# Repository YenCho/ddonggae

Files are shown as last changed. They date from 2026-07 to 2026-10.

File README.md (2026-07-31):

<div align="center">

# DDONGGAE&ensp;똥개

<h3><b>D</b>NN-based <b>D</b>etection of <b>O</b>bjects with <b>N</b>avigation<br>
and <b>G</b>oal-oriented <b>G</b>rasping for <b>A</b>utonomous <b>E</b>rrands</h3>

<p><b>An autonomous mobile manipulator that finds, identifies, grasps and stores 8 cm objects<br>
in a 4 m × 4 m arena inside a 3-minute round, computing everything on board a Jetson Orin Nano.</b></p>

<p><b>no Nav2&emsp;·&emsp;no AMCL&emsp;·&emsp;no TF tree&emsp;·&emsp;not one hand-labelled training image</b></p>

<p>🏆 <b>1st of 16 teams (우승)</b> — SNU AI ROBOT CHALLENGE 2026 (Seoul National University)</p>

<p>


</p>

<p>



</p>

<p>






</p>

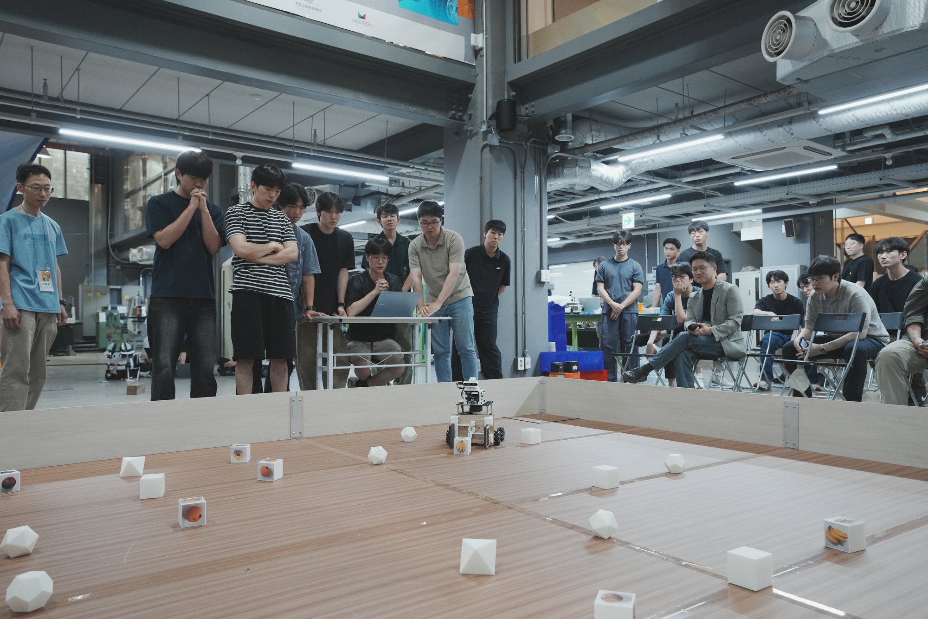
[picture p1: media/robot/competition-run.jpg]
DDONGGAE running a match in the 4 m x 4 m arena, carrying a fruit cube in its gripper while the other teams watch from behind the arena wall


<p><i>DDONGGAE mid-match: 28 white 3D-printed objects on a 50 cm grid, two announced target classes,<br>
180 seconds, one gripper — so every point is a round trip across the arena.</i></p>

<b><a href="#result">Result</a>&emsp;·&emsp;<a href="#what-it-does">What it does</a>&emsp;·&emsp;<a href="hardware/README.md">Hardware</a>&emsp;·&emsp;<a href="perception/README.md">Perception</a>&emsp;·&emsp;<a href="navigation/README.md">Navigation</a>&emsp;·&emsp;<a href="mission/README.md">Mission</a>&emsp;·&emsp;<a href="simulation/README.md">Simulation</a>&emsp;·&emsp;<a href="docs/README.md">Docs</a></b>

</div>

---

### Why 똥개?

**똥개** (*ddong-gae*) is Korean for a mongrel — a scruffy, unpedigreed street dog. It is an
insult and a term of affection at the same time, depending entirely on how you say it. Ours was
said with affection, at volume: **달려라 똥개** — *"run, mutt!"* — which became the team chant.

The name came from the robot's single most consequential limitation: one gripper, **one object at a
time**. That turns a match from a search problem into a running problem — drive out, pick up, run
it all the way back to the bin in the opposite corner, repeat. Seven objects in three minutes is
seven round trips, so the robot spends almost the whole match sprinting across the arena carrying
one cube. It is a very familiar image.

So the joke is also the design brief. A **25-second budget per object** falls straight out of it
(180 s ÷ 7), and nearly every engineering decision here — the free "highway" along the empty band
of the arena, the street router, deleting Nav2 for a localiser 17–22× faster, cutting rotation
because turning was collapsing the pose estimate — exists to make those round trips shorter.

<table>
  <tr>
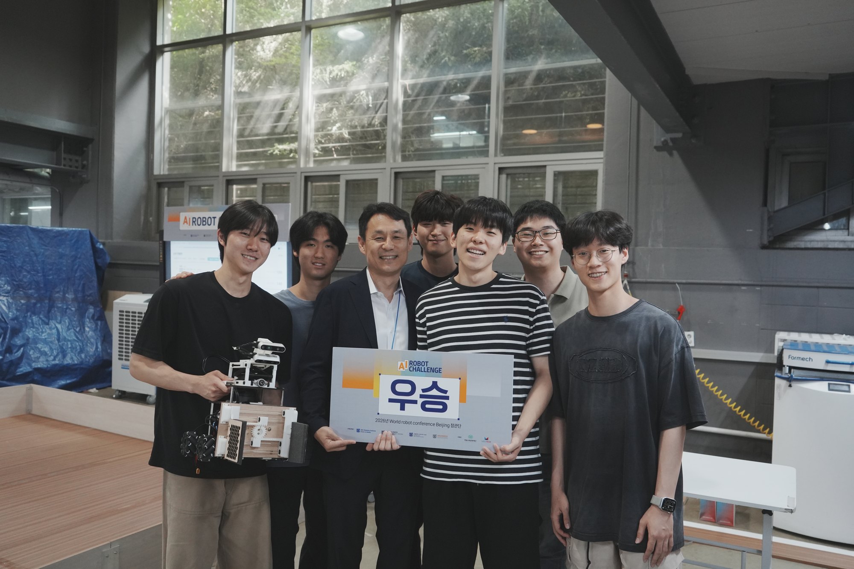
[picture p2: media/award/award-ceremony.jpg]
Team 14 holding the winners' placard and the robot
    <td width="50%"></td>
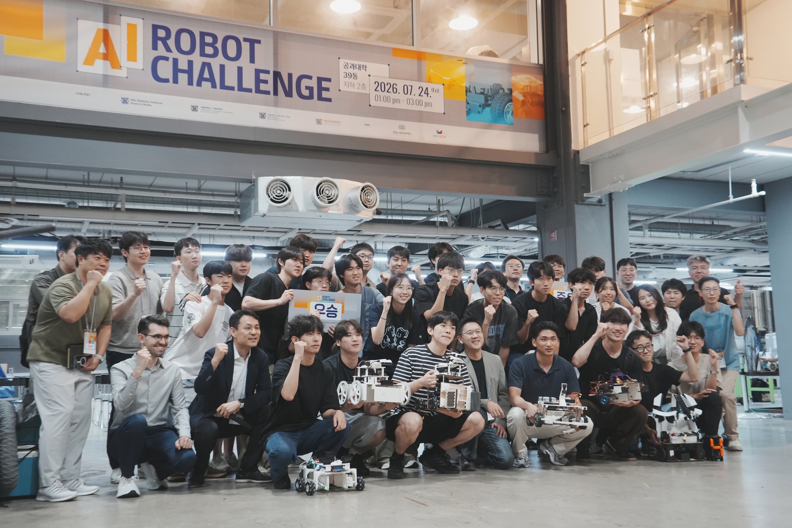
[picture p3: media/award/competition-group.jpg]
All SNU AI ROBOT CHALLENGE 2026 participants with their robots under the event banner
    <td width="50%"></td>
  </tr>
</table>

<!-- STILL TO ADD:
     VIDEO       replace every <YOUTUBE_URL> in this file, media/video/README.md
                 and docs/07-results-and-lessons.md with the organisers' recording URL -->

> Full competition video: `<YOUTUBE_URL>` *(to be added when the organisers publish it)*

---

## Result

**1st of 16 teams**, SNU AI ROBOT CHALLENGE 2026. Five teams reached the final; the final standing is
the sum of two matches, 200 points maximum, ties broken by fastest mission completion.

<picture>
  <source media="(prefers-color-scheme: dark)" srcset="docs/assets/final-standings-dark.svg">
  Final standings: Team 14 150, Team 7 140, Team 8 110, Team 16 100, Team 10 50 — each bar split into its two match scores
</picture>

Our two rounds, with the target classes drawn for each:

| | Targets | Collected | Score |
|---|---|---|---:|
| Final 1 | octahedron · pineapple | 3 fruit cubes | 60 |
| Final 2 | octahedron · banana | 3 shapes + 3 fruit cubes | 90 |

Scoring is 10 points per shape object and 20 per fruit cube, so one perfect match is 100 (4 shapes +
3 fruit cubes). We reached the final by placing in the qualifiers, which are weighted 10 % for the
first round and 90 % for the second; we scored 60 in both.

No match we ever ran was close to perfect, and we lost points three separate ways — all three are
documented at the same level of detail as the wins:

- **Qualifiers** — the apple printed on the arena cubes was a **yellowish, under-ripe apple**, not
  the red one announced beforehand. Our face model, trained on synthetic renders of a red apple,
  mis-predicted it. A textbook train/deploy colour domain gap.
- **Final 1** — the **gripper stopped reporting**. The robot routed to each object correctly, but
  the OpenRB board went quiet mid-match: one octahedron was carried and released without the grasp
  ever being confirmed (almost certainly an empty hand, and it scored nothing), and two more were
  refused outright because the gripper actively declared itself empty. Landing that one grasp would
  have made the match 70, not 60 — the run's own estimate. We also went 189.8 s against a 180 s
  budget, and the runner crashed on a seventh object seconds after it was dropped in.
- **Final 2** — **ran out of time.** The 180 s timeout expired while the last object was being
  grasped, and only what is inside the box at time-up scores.

Full post-mortem with measured numbers: [`docs/07-results-and-lessons.md`](docs/07-results-and-lessons.md).

---

## What it does

The robot starts in a 40 × 40 cm corner zone of a 4 m × 4 m walled arena that contains 28 white
3D-printed objects on a known 42-point, 50 cm grid — polyhedra worth 10 points each and cubes with
fruit photographs on three of their six faces worth 20 each. Two target classes are announced, the
second of them **one minute** before the start signal, after which nobody may touch the computer.
Within 180 seconds and with every computation on board a Jetson Orin Nano, it drives to the arena
centre, raises a camera mast, takes twelve stitched captures at 30° steps, votes each detection onto
the 42-cell grid, then works through the confirmed targets — the 20-point fruit set first, and in
the two finals ranked by expected value rather than distance — re-verifies each identity at close
range, grasps it, carries it to the storage box at the far end of the start wall and drops it on a
precomputed slot. Picking up the wrong object costs twice its value, so refusing to pick is a
legitimate — often optimal — outcome, and the collection loop is built around that asymmetry.

```mermaid
flowchart LR
  subgraph SENS["Sensors"]
    direction TB
    CAM["2x RealSense D435/D435i<br/>on a lifting mast"]
    LID["RPLIDAR A2M12"]
    IMU["D435i gyro-z"]
  end

  subgraph ROS["ROS 2 Humble — one process per device, plus two brains"]
    direction TB
    RS["realsense2_camera x2"]
    SLL["sllidar_node<br/>+ scan watchdog"]
    RUN["match_runner.py<br/>stitch -> A1 -> face -> depth -> 42-cell grid<br/>+ the match state machine"]
    ARENA["arena_control_node<br/>known-map wall-range localisation<br/>+ mecanum goal controller"]
    MUX["cmd_vel_mux"]
    MEC["mecanum_bridge_node"]
    GRIP["gripper_bridge_node"]
  end

  subgraph ACT["Actuators — firmware owns the loops"]
    direction TB
    UNO["Arduino UNO<br/>4x wheel velocity PID<br/>+ trapezoidal position moves"]
    ORB["OpenRB-150<br/>Dynamixel XC330 x2"]
    WHL["4 mecanum wheels"]
    GM["parallel gripper + camera mast"]
  end

  CAM --> RS -->|"RGB 1920x1080 + aligned depth"| RUN
  LID --> SLL -->|"/laser_scan"| ARENA
  IMU -->|"/imu/data"| ARENA
  RUN -->|"STOP, then JSON goal {x,y,yaw} (fallback path)"| ARENA
  ARENA -->|"/arena_lightweight/status — pose at 20 Hz"| RUN
  RUN -->|"/cmd_vel_direct at 20 Hz (street closed loop)"| MUX
  ARENA -.->|"/cmd_vel_direct (goal following, fallback)"| MUX
  MUX --> MEC
  RUN -->|"/base/move_relative"| MEC
  RUN -->|"/gripper/command, /lift/command"| GRIP
  MEC -->|"serial 115200"| UNO --> WHL
  GRIP -->|"serial 115200"| ORB --> GM
```

Nine long-lived processes, no custom message package — every structured payload is a
`std_msgs/String` carrying JSON, so the whole graph is `ros2 topic echo`-readable with nothing
built. The exhaustive graph, with every topic, QoS profile, JSON schema and serial line, is in
[`docs/03-ros2-interfaces.md`](docs/03-ros2-interfaces.md).

The solid `/cmd_vel_direct` edge is the one that carried every match. The mission runner sends the
arena node a `STOP` first — releasing its goal following — and then drives the base itself at 20 Hz
through [`navigation/street_nav.py`](navigation/street_nav.py), because the corridors are only
25 cm wide and the gripper sticks 26 cm out in front. Goal following is the dashed edge: the
fallback we kept for the legacy route (`--nav legacy`).

---

## The three parts

### [Hardware](hardware/README.md)

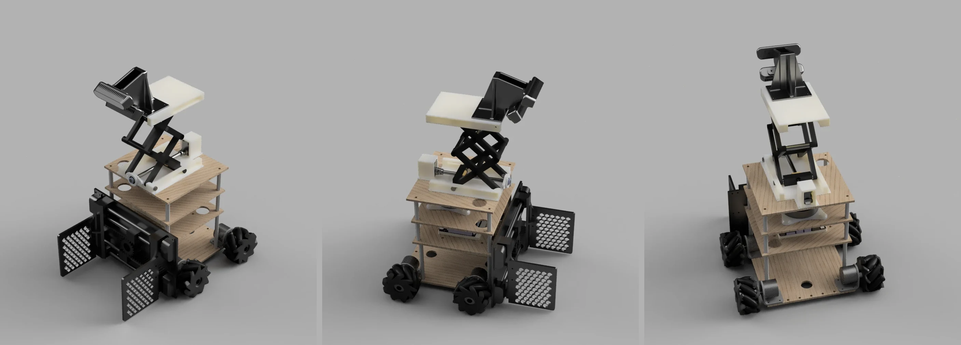
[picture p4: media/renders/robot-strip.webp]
The DDONGGAE robot rendered from three angles 120 degrees apart, mast raised


A 4-wheel mecanum base with a three-deck plate stack, a servo-driven camera mast carrying both
RealSense units, and one parallel gripper. The mast exists for one reason: it goes up for the
centre scan. A fruit cube's three photographed faces are its top and one opposing pair of sides,
so the **top** face is the only one visible from every direction — from chassis height it is
edge-on and contributes nothing, and whether you see a photograph at all comes down to which way
the cube happens to be turned. The 148.9 mm of stroke puts the top camera at 0.4986 m and steepens
the look-down enough to read those top faces, while also cutting how much the objects occlude each
other. Two microcontrollers own all motion primitives: an
Arduino UNO runs the four wheel-velocity PIDs and synchronised trapezoidal position moves
(`d dx dy dyaw` → `DONE,move`), and an OpenRB-150 owns the gripper and the mast lift on a single
tty. The headline fact is that two of the drive constants are **fitted, not measured** —
`wheel_radius_m` 0.0388 against a physical 0.040, and a rotation geometry of 0.198 m against a
physical 0.275 m — because a commanded 90° yaw produced 158° of real rotation until they were
recalibrated against the gyro. Copy the physical values and every position move is wrong.

### [Object detection](perception/README.md)

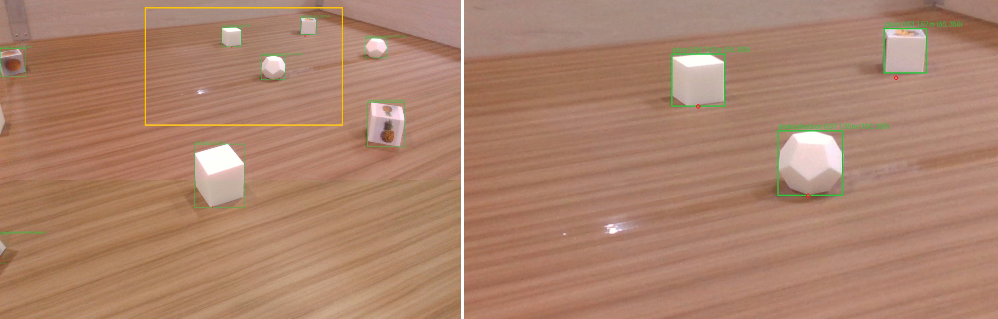
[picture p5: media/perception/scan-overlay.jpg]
A1 and face detections drawn on a stitched arena frame during the centre scan, with an enlarged panel showing the per-detection labels


Three stages, in the configuration that played the finals: full-frame A1 shape segmentation on the
stitched dual-camera frame (`cube_like_object` / octahedron / dodecahedron / icosahedron), then
every cube crop batched into one 224 × 224 BGR face-identity pass (apple / orange / banana /
pineapple / plain), then a binary pair verifier (MobileNetV3, ONNX) as a second opinion on the
fruit faces, then depth back-projection into the map and a per-cell vote across the 12-shot spin.

Both YOLO stages started from **zero hand-labelled images** — the training set was rendered in
BlenderProc. That stopped being the whole story on the last night: the face weight that played the
two finals is a fine-tune on photographs of the actual arena objects, hand-checked by an operator,
and the banana/pineapple verifier that ran beside it was retrained the same way. On a held-out
arena set (60 scenes, 573 objects) A1 scores box mAP50 0.831 / mAP50-95 0.729 — published next to the
0.9941 it scores on the split it was trained on, because that is the number that would have
fooled us.

### [Navigation](navigation/README.md)

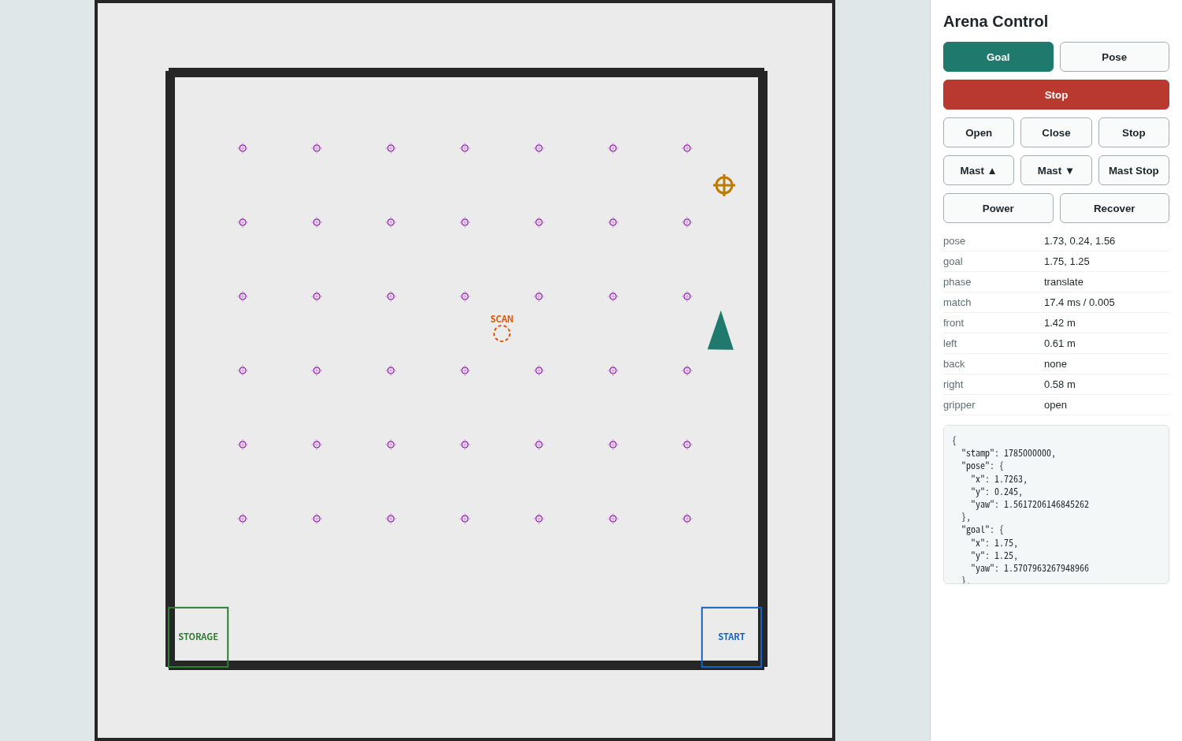
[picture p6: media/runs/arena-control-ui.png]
The arena control web UI: the 42-point grid, the storage and start zones, the scan point, the robot pose and the clicked goal, beside a panel of buttons and live metrics


One `rclpy` node, no Nav2 and no framework underneath it. The arena is a known empty rectangle and
the LiDAR plane at 0.32 m clears every 8 cm object, so every return is a wall: the localiser scores
each beam against the **analytic** ray/rectangle range of the four walls, ~30 float operations per
beam, pure Python standard library with no numpy in the hot path.

The approach we replaced — generic occupancy-grid scan matching, the Nav2/AMCL way — took
**345–449 ms** per solve on this robot. Ours takes **20.35 ms** on a synthetic 1080-beam scan and a
median of **28.2 ms** on the Jetson across 2,132 real scans. At a 10 Hz LiDAR that is the difference
between running 3–4 scans behind and comfortably inside one scan period; the old latency is why the
pose used to jump and the driven path used to bend. Yaw comes from integrating gyro-z forward
between scans, which is what makes a 90°-symmetric square arena solvable at all.

The mission layer that drives all three — [`mission/match_runner.py`](mission/README.md), 5,291
lines — and the [Isaac Sim kinematic surrogate](simulation/README.md) that ran the *same* file
against ground truth are documented separately.

---

## Highlights

- **We deleted Nav2 and measured why.** Full occupancy-grid scan matching: 345–449 ms per solve,
  with pose yaw jumping and driven paths bending. The closed-form wall-range replacement is ~90
  lines and 17–22× faster. The price is stated too: the map must be a known correct rectangle, the
  initial pose must be seeded by an operator, and there is no dynamic obstacle avoidance worth the
  name. [ADR-0001](docs/adr/0001-drop-nav2.md).
- **Every weight started from BlenderProc renders — and the last night broke that.** Right up to the
  qualifiers, nothing in the project had been hand-labelled: when the organisers clarified the face
  rule four days out, the fix was three lines and a re-render instead of a re-annotation. Then the
  arena's apple turned out to be the wrong colour, and the answer was photographs of the real
  objects, an operator relabelling ~74 crops by eye and dropping ~60 more, and an overnight
  fine-tune. That weight, and a banana/pineapple verifier retrained the same way, are what played
  the two finals. The synthetic-only claim is true of the qualifiers, not of the trophy.
- **Two runtime contracts that fail silently.** Mind the RGB↔BGR convention, and mind the gap
  between the size the model was trained at and the `imgsz` it is called with on the robot. Get
  either wrong and accuracy collapses — with no error raised and every log line still looking
  healthy. Details in [`perception/docs/models.md`](perception/docs/models.md).
- **Batch, don't loop: 3.86×.** Five crops through one `predict()` call take 10.9 ms; the same five
  crops in a Python `for` loop take 42.2 ms. Nothing about the model changes. The same discipline
  took the whole pipeline from 1.29 FPS (the earlier 4-stage cascade) to 3.83 FPS on an identical
  30 s capture.
- **The street router.** Because the rulebook only ever places objects on a 50 cm grid, the midlines
  between grid rows and columns are 25 cm corridors that are free *by construction* — so the router
  snaps onto a fixed street grid and verifies clearance instead of inflating a costmap (a 0.31 m
  circumscribed inflation marks every legal street blocked). After the 2026-07-20 fix: 0 of 28
  targets intruded on an object cell, minimum clearance 0.250 m, against 6 intrusions and 4.8 cm
  before it.
- **Sensorless grasp verification.** The gripper has no force sensor and its current reading is
  useless (an empty hand saturates at ~113 raw against a goal of 120). The *settled finger-position
  gap* separates cleanly instead: 3.0–3.2° empty versus 14.1° holding an icosahedron, threshold
  8.0°, and the whole check fits in 0.85 s.
- **The match was planned in simulation, not on the robot.** A perfect round is 7 objects in 180 s
  — a **25-second budget per object** — and a wrong pickup costs *double* the object's value. The
  Isaac Sim kinematic surrogate runs `mission/match_runner.py` unmodified against known ground
  truth, with a per-object phase breakdown (route / face / approach / grasp / carry), so time could
  be attributed rather than guessed at. That is where excess rotation was identified as the thing
  collapsing the localiser, and where an ~8 s deadband-parking-plus-settling grind was found and
  removed. No physics required — just the real state machine, a real map and a clock.
  [`simulation/README.md`](simulation/README.md)

---

## Quickstart

Three of these need no robot, no GPU, no ROS installation and no model weights.

```bash
git clone https://github.com/YenCho/ddonggae
cd ddonggae

# 1. the mission logic, self-testing: GT parser, street router (incl. the 28-object
#    regression case), 42-cell snap, storage slot layout, competition candidate filter
python3 mission/match_runner.py --offline

# 2. the unit tests that need no ROS — 47 pass in ~2 s
#    (localisers, mecanum kinematics + odometry, stitch geometry, grasp alignment, web UI)
python3 -m pytest tests/ -q --ignore=tests/test_controllers.py

# 3. with ROS 2 Humble: build the four packages, then run the full suite
source /opt/ros/humble/setup.bash
colcon build --symlink-install --base-paths hardware/ros2 navigation/ros2 third_party
source install/setup.bash && python3 -m pytest tests/ -q

# 4. the perception weights (not in git — Ultralytics derivatives, AGPL-3.0)
scripts/fetch_models.sh
```

`match_runner.py --offline` prints its self-test in Korean; the shipped script logs in Korean
throughout, and the reasoning in those log lines and code comments is translated into these docs
rather than deleted.

Then: [`docs/04-getting-started.md`](docs/04-getting-started.md) to bring the stack up on a robot,
and [`docs/05-field-runbook.md`](docs/05-field-runbook.md) for the competition-day procedure as it
was actually operated. Read [`docs/04` §10](docs/04-getting-started.md) first if you intend to
reproduce results — the stitch calibration, the camera mount geometry, the venue photometry and the
TensorRT engines are ours and do not transfer.

---

## Repository layout

```
.
├── hardware/        the machine: Arduino UNO + OpenRB-150 firmware, the two ROS 2 bridge
│                    packages, the numbered 00..53 bring-up/calibration chain, URDF + meshes
├── perception/      fieldlib.py (the shared runtime contract), geometry.py, the stitch and
│                    photometry calibration, training entry points, offline evaluators
├── navigation/      arena_lightweight_control — the entire Nav2-free localisation and
│                    control stack, its map, its launch file and its web operator console
├── mission/         match_runner.py, the 5,291-line program that played every match, plus
│                    field_autopilot.py (bring up / health-check / capture / teleop / down)
├── simulation/      Isaac Sim kinematic surrogate: same topics, same mission file, known
│                    ground truth. Explicitly not a physics validator
├── docs/            01..08 numbered guides, five ADRs, CREDITS  ->  docs/README.md
├── scripts/         the wrappers actually typed in the field, run_match_day.sh first
├── tests/           pytest; no robot, no GPU
├── third_party/     vendored sllidar_ros2 (BSD-2), pinned to the revision that competed
└── media/           robot renders, competition photographs, the scan clip and run figures
```

---

## What didn't work

Three ideas that looked obviously correct, were built, were measured, and lost — a binary
apple-vs-orange / banana-vs-pineapple verifier pair that was *more* accurate in isolation yet cost
11 points of face-level accuracy as a decision rule (85.7 % with verifiers off versus 74.3 % for the
best gated configuration, over a 780-configuration sweep on 175 real face patches) — though that
verdict was about the *synthetic-trained* verifiers, and a banana/pineapple one retrained on real
photographs earned its place back in the finals; a distance gate
that was tuned for three weeks and turned out to be masking a two-line inference bug; and
ground-contact ranging, which is exact for a cube and systematically long for a sphere-like
polyhedron, producing 0/4 icosahedron grasps on 2026-07-20 before it was replaced by depth
sampling.

All three, plus the three competition failures and ten transferable lessons, are in
[`docs/07-results-and-lessons.md`](docs/07-results-and-lessons.md).

---

## Team

Seven people built this robot. Names, GitHub accounts, how the work split, and the tooling
disclosure are in [`docs/CREDITS.md`](docs/CREDITS.md).

---

## License, citation, acknowledgements

The code and documentation in this repository are **MIT** licensed ([`LICENSE`](LICENSE)). Two
things in it are not:

- **Model weights** are Ultralytics YOLO derivatives and therefore **AGPL-3.0**. They are published
  as GitHub Release assets, fetched by `scripts/fetch_models.sh`, and are not in this tree.
- **Training textures and backgrounds are not redistributed.** The fruit-face texture pool is
  built from three public datasets (65 % Fruits-360, CC BY-SA 4.0, among others — web-scraped
  images were deliberately excluded), but the share-alike and attribution obligations, and the
  COCO 2017 background terms, are theirs to carry; only the generation and filtering scripts are
  published. See [`NOTICE`](NOTICE) for the full third-party list, including the vendored Slamtec
  `sllidar_ros2` driver (BSD-2-Clause).

The competition rules are the organisers' property and are paraphrased, never reproduced, in
[`docs/01-competition-and-rules.md`](docs/01-competition-and-rules.md).

To cite this work, use [`CITATION.cff`](CITATION.cff) (GitHub's "Cite this repository" button reads
it directly):

```bibtex
@software{ddonggae_2026,
  title  = {DDONGGAE: an autonomous polyhedron-collecting robot},
  author = {Cho, Yeonwoo and Kim, Jaeyoung and Jang, Minjoon and Lim, Junhwan
            and Kim, Minseok and Kim, Junseo and Han, Seojun},
  year   = {2026},
  url    = {https://github.com/YenCho/ddonggae},
  license = {MIT}
}
```

**Acknowledgements** — the organisers of the SNU AI ROBOT CHALLENGE 2026
for the arena, the rulebook and the venue; Slamtec, ROBOTIS, Intel RealSense, NVIDIA (Isaac Sim),
Ultralytics and the BlenderProc and Blender projects, whose work this robot is built on top of and
whose licences are enumerated in [`NOTICE`](NOTICE).

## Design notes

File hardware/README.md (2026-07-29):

# Hardware

<p align="center">
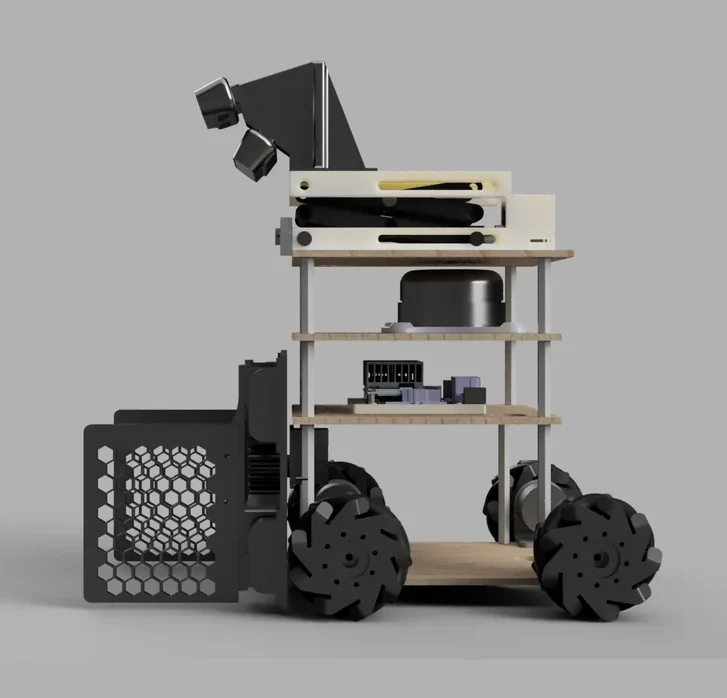
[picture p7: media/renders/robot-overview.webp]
Render of the DDONGGAE robot from the side: mecanum base, three equipment decks, the lowered camera mast and the parallel gripper
  
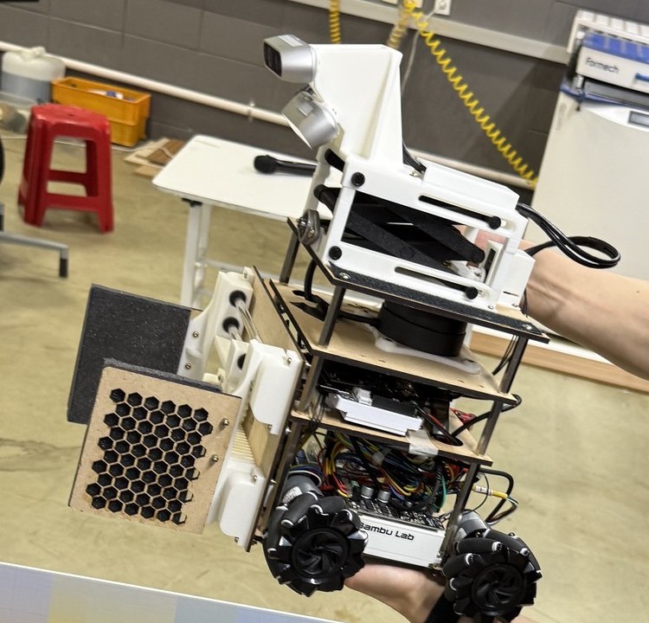
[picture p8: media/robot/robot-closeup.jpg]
The robot as built, held up after the final: hex-mesh gripper jaws, the mast with both RealSense units, the lidar, the wired decks and the mecanum wheels
  
</p>
<p align="center"><em>The CAD and the thing that played the matches, from about the same angle.
Wheel centres are 0.30 m front to rear and 0.25 m across.</em></p>
Everything on this robot that touches a wire: two firmware images, the two ROS 2 packages
that speak their serial protocols, the calibration constants those bridges load, the
bring-up chain that measures those constants, and the CAD.

This is the machine that won 1st place of 16 teams at the SNU AI ROBOT CHALLENGE 2026 (qualifiers 60 + 60 pts, finals 60 + 90 = 150 pts).

---

## 1. What the robot is

A 4-wheel mecanum differential-strafe base, roughly 0.30 m (wheel centre to wheel centre,
front to rear) × 0.25 m (left to right), with a three-deck plate stack, a servo-driven
camera mast, and a single parallel gripper at the front. It works a 4 m × 4 m arena in
3-minute rounds: find objects on a known 42-point grid, drive to one, grasp it, carry it
to the storage box, repeat.

| Subsystem | What it is | Where it is defined |
|---|---|---|
| Drive | 4 × JGB37-520 12 V 333 rpm gearmotor with quadrature encoder, mecanum wheels in X configuration | [`docs/wiring-and-firmware.md`](docs/wiring-and-firmware.md) |
| Motor drivers | 2 × Cytron MDD10A (2 channels each, PWM + DIR sign-magnitude) | [`docs/wiring-and-firmware.md`](docs/wiring-and-firmware.md) |
| Motion controller | Arduino UNO — 4 encoders, 50 Hz velocity PID, cascaded position loop, trapezoidal profiles | `firmware/arduino_mecanum/mecanum_encoder_control.ino` |
| Gripper | Dynamixel XC330 (ID 0), parallel jaws, current-based position mode | [`docs/gripper-and-mast.md`](docs/gripper-and-mast.md) |
| Camera mast | Dynamixel XC330 (ID 12), multi-turn lift, 148.9 mm measured stroke | [`docs/gripper-and-mast.md`](docs/gripper-and-mast.md) |
| Servo controller | OpenRB-150 — one USB tty, one Dynamixel bus at 1 Mbps, Protocol 2.0 | `firmware/openrb_gripper_mast/openrb_gripper.ino` |
| Cameras | Intel RealSense D435 (top) + D435i (near) — both ride the mast | `ros2/robot_bringup/launch/real_competition_bridge.launch.py` |
| LiDAR | Slamtec RPLIDAR A2M12, 256000 baud, mounted at `base_link` z = 0.262 m, yaw = π | `ros2/robot_bringup/launch/real_competition_bridge.launch.py:192-212` |
| Gyro | The D435i's IMU (`enable_bottom_imu` default `true`, remapped to `/imu/data`) — used by the localizer to make arena yaw observable | `ros2/robot_bringup/launch/real_competition_bridge.launch.py:57-58,150` |
| Compute | NVIDIA Jetson Orin Nano — the two RealSense units and the LiDAR plug into it directly; the UNO and the OpenRB-150 go through a powered USB hub, which held their ttys far more reliably than the Jetson's own ports did | [`docs/wiring-and-firmware.md`](docs/wiring-and-firmware.md#2-boards-buses-and-who-owns-what) |
| Power | 12 V battery → both MDD10A boards; encoders and logic off the Arduino 5 V rail; common ground is mandatory. Boot the Jetson with the 12 V kill switch **off** and switch it on afterwards, or the OpenRB-150 will not enumerate reliably | [`docs/wiring-and-firmware.md`](docs/wiring-and-firmware.md#boot-the-jetson-with-the-12-v-kill-switch-off) |

<p align="center">
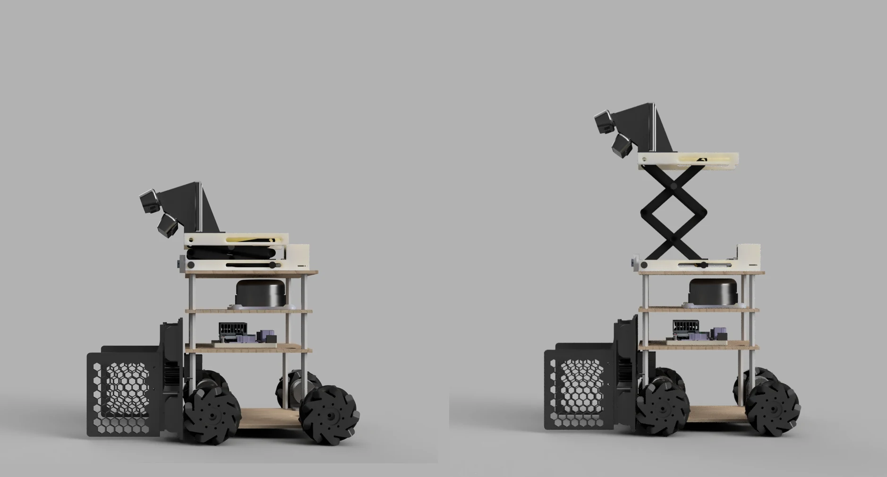
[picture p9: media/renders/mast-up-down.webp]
The robot rendered from the side with the camera mast lowered and raised, at the same scale and ground line
  
</p>
<p align="center"><em>The one moving part that changes what the robot can see: the mast down (left) and up
(right), same scale, same ground line. The stroke is 148.9 mm measured. Both RealSense units ride the
top plate, so the two heights are two camera extrinsics and two stitch calibrations — most of what
<a href="../perception/README.md">perception/</a> has to keep straight follows from this picture.</em></p>

It goes up for exactly one thing: the centre scan. What separates a 20-point fruit cube from a
10-point plain one is a photograph on three of its six faces — the **top** face and one opposing
pair of sides. Only the top face is visible from every direction: the two fruit sides face away
half the time, depending on how the cube was set down. And from chassis height the top face is
edge-on, contributing a few pixels at the 1–2 m ranges the scan works at. So a mast-down scan is
left guessing on cube identity from an unlucky yaw. The 148.9 mm lift steepens the look-down enough
to read the top faces regardless of yaw, and buys less mutual occlusion between objects across a
2.15 m scan radius on the way. Everything else in the match runs mast-down — the pre-shot and the
pre-grasp re-check are both short-range work for the near camera — which is why the descent is
commanded the instant the last scan frame is taken. Full argument, with the measured fruit-face
hit rates: [`perception/docs/grid-voting.md`](../perception/docs/grid-voting.md).

Deck geometry, as modelled in `cad/urdf/robot_mk3_mecanum_sim_80mm.urdf` (collision boxes,
so these are the plate outlines, not machining drawings):

| Deck | Size | Height above ground |
|---|---|---|
| Lower plate | 190 × 250 × 6 mm | 0.173 m |
| Middle plate | 190 × 210 × 6 mm | 0.258 m |
| Upper plate | 190 × 170 × 6 mm | 0.333 m |

Modelled chassis mass is 2.4 kg (simulation value, not a weighed figure).

### Three microcontrollers, three rules

1. **Arduino UNO owns motion.** It is not a dumb PWM slave. Geometry, both PID sets,
   per-wheel motor and encoder polarity and even the driver's PWM encoding style are all
   runtime serial commands, and a single `d <dx> <dy> <dyaw>` makes the firmware run a
   synchronized 4-wheel trapezoidal move and report the residual error per wheel. There is
   no host-side control loop on the mecanum path.
2. **OpenRB-150 owns the gripper *and* the mast, on one tty.** Opening that serial port
   from a second process toggles DTR, reboots the board, wipes the mast's RAM-held home
   position and force-opens the gripper. Exactly one process may hold it — see
   [the one-process rule](docs/gripper-and-mast.md#5-one-process-owns-the-tty).
3. **The LiDAR is treated as unreliable by design.** `laser_scan_watchdog_node`
   republishes `/scan_raw` at a fixed rate onto `/laser_scan` (+ a `/scan` alias), holds a
   stale scan for a bounded window and can emit an explicit empty scan on total loss, so
   the localizer never sees a gap.

---

## 2. Directory map

```
hardware/
├── firmware/
│   ├── arduino_mecanum/mecanum_encoder_control.ino   THE flashed competition firmware (UNO)
│   └── openrb_gripper_mast/openrb_gripper.ino        THE flashed competition firmware (OpenRB-150)
├── ros2/
│   ├── robot_hardware/      mecanum_bridge_node, gripper_bridge_node, kinematics, odometry
│   └── robot_bringup/       real_competition_bridge.launch.py, cmd_vel mux, scan watchdog, real.yaml
├── bringup_tools/           numbered rebuild chain 00..53 (flash → signs → CPR → PID → LiDAR → accuracy)
├── calibration/motor_pwm/   PWM→rad/s sweeps (legacy differential-drive generation)
├── cad/
│   ├── urdf/                mecanum URDF (80 mm wheels) + the generator that produced it
│   ├── meshes/              STL visual meshes referenced by the URDF
└── docs/
    ├── bom.md                    bill of materials
    ├── wiring-and-firmware.md    pin map, MDD10A, both serial protocols, the PID cascade
    └── gripper-and-mast.md       sensorless grasp detection, mast homing, the one-tty rule
```

ROS 2 nodes shipped here (`ros2/robot_hardware/setup.py`, `ros2/robot_bringup/setup.py`):

| Node | Role |
|---|---|
| `mecanum_bridge_node` | **The competition base driver.** `/cmd_vel_motor` → serial `m`; `/base/move_relative` → serial `d` → `/base/move_result`; `STATE` stream → `/chassis/odom`, `/joint_states`, `/motor/state` |
| `gripper_bridge_node` | Sole owner of the OpenRB tty. `/gripper/command`, `/lift/command` → serial; `/gripper/state`, `/lift/state`, `/gripper/grasp` |
| `cmd_vel_mux_node` | Priority mux `/cmd_vel_direct` > `/cmd_vel` > `/cmd_vel_nav` → `/cmd_vel_motor`, each with a 0.4 s staleness timeout, zero Twist at 30 Hz when all sources go stale |
| `laser_scan_watchdog_node` | `/scan_raw` → `/laser_scan` + `/scan`, fixed rate, bounded stale-hold |
| `motor_bridge_node` | **Legacy** differential-drive driver (MK3, host-side PI + calibrated PWM feedforward). Superseded by the 2026-07-14 mecanum conversion; retained so the diff→mecanum history is legible |

---

## 3. How to rebuild it

### 3.1 Order the parts

Start from [`docs/bom.md`](docs/bom.md). Two things there are not substitutable without
code changes:

- **All four motors must have encoders.** The position loop is per-wheel; a rear wheel
  without an encoder cannot participate in a synchronized move.
- **The motor driver must be sign-magnitude (PWM = speed, DIR = direction).** The firmware
  supports the older inverted-PWM style too, but only as a runtime `mstyle` switch, and
  the shipped defaults assume MDD10A.

### 3.2 Assemble and wire

Follow [`docs/wiring-and-firmware.md`](docs/wiring-and-firmware.md). The one mechanical
trap: mecanum wheels must be mounted in **X configuration** viewed from above (FL/RR
rollers tilt one way, FR/RL the other). Mount them in O configuration and every strafe
command becomes a rotation.

### 3.3 Flash and calibrate

The bring-up chain in `bringup_tools/` is numbered in execution order, and **each script
prints the exact constants to paste into `ros2/robot_bringup/config/real.yaml`**. Scripts
00–31 talk to the Arduino over raw serial and require the ROS bridge to be stopped; 40+
require the ROS stack to be running.

| Step | Tool | What it produces | Robot state |
|---|---|---|---|
| 00 | `00_flash_firmware.sh` | Compiles and uploads via `arduino-cli` (`arduino:avr:uno`) | Bridge stopped |
| 10 | `10_wheel_selftest.py` | The firmware `sign` line and the `motor_signs` / `encoder_signs` YAML snippet | On blocks, wheels free |
| 20 | `20_encoder_cpr_calib.py` | `encoder_cpr` — turn each wheel N revolutions by hand and count ticks | On blocks |
| 30 | `30_pid_step_tune.py` | Velocity PID gains from step responses (rise / overshoot / steady-state error per wheel) | On blocks |
| 31 | `31_pid_floor_verify.py` | Re-verifies those gains **under floor load**, forward and reverse | On the floor |
| 40 | `40_lidar_orientation_check.py` | Recommended `base_scan_yaw` — catches a LiDAR mounted 180° out | LiDAR driver up |
| 50 / 51 / 52 | `50_move_accuracy.py`, `51_move_accuracy_lidar.py`, `52_single_wall_verify.py` | Effective wheel radius and effective rotation geometry, from tape measure, from LiDAR localization, or from a single wall + gyro | Bridge running |
| 53 | `53_max_speed.py` | The drivetrain saturation point per axis | Bridge running, speed caps raised |

### 3.4 Understand which constants are "effective", not physical

This is the most important thing to carry over if you rebuild. Two numbers in
`ros2/robot_bringup/config/real.yaml` are **fitted**, not measured with a ruler, and
copying the physical values instead will make every position move wrong:

| Parameter | Shipped value | Physical value | Why they differ |
|---|---|---|---|
| `wheel_radius_m` | **0.0388** | 0.040 (80 mm wheel) | 2026-07-15: with 0.034 configured, commanded straight-line moves travelled 112–116 % of the command against a LiDAR reference. The effective contact radius absorbs roller slip and tyre compression. |
| `half_length_m` + `half_width_m` | **0.108 + 0.090 = 0.198** | 0.150 + 0.125 = 0.275 | 2026-07-15, after re-seating the wheels in X configuration and recalibrating against the gyro: a commanded 90° yaw produced 158° of real rotation. The rotation factor `(L+W)` is fitted, not geometric. |

Re-measure both with `bringup_tools/51_move_accuracy_lidar.py` (or `52_single_wall_verify.py`
if you have no arena) whenever the wheels or the floor surface change.

### 3.5 Run it

```bash
source /opt/ros/humble/setup.bash
source install/setup.bash
DRIVE_TYPE=mecanum bash scripts/run_real_competition_bridge.sh
```

> **`DRIVE_TYPE=mecanum` is not optional.** `real_competition_bridge.launch.py` declares
> `drive_type` default `diff`
> (`ros2/robot_bringup/launch/real_competition_bridge.launch.py:134-139`) and the wrapper
> script defaults `DRIVE_TYPE=diff`, both inherited from the differential-drive generation.
> Omit the export and you get the legacy differential-drive bridge talking to mecanum
> firmware, which will not move correctly.

The launch also hard-codes device paths that are specific to one Jetson carrier board and
one set of boards (`/dev/serial/by-path/platform-3610000.usb-...`, camera serial numbers,
`/dev/rplidar`). Replace these with your own `by-id` paths or udev rules before first run.

---

## 4. Document map

| Document | Read it for |
|---|---|
| [`docs/bom.md`](docs/bom.md) | Parts list, quantities, substitution notes |
| [`docs/wiring-and-firmware.md`](docs/wiring-and-firmware.md) | Arduino pin map, MDD10A and encoder wiring, the complete serial grammar for **both** boards, the PID cascade, the firmware-owned motion primitives, and the five serial-layer bugs that were fixed on the field |
| [`docs/gripper-and-mast.md`](docs/gripper-and-mast.md) | The XC330 gripper's safe arc and current limits, sensorless grasp detection by settled position gap, the camera mast's limit-switch-free homing, and the one-process-owns-the-tty rule |
| [`bringup_tools/README.md`](bringup_tools/README.md) | The bring-up chain, in the original Korean |
| `firmware/arduino_mecanum/README.md` | Original Korean firmware notes. **Its pin table is stale** — use the table in `docs/wiring-and-firmware.md` |
| [`../docs/03-ros2-interfaces.md`](../docs/03-ros2-interfaces.md) | The whole sensors → topics → bridges → actuators graph |

---

## 5. Known hardware limitations, published deliberately

- **The rear-right encoder A channel is dead.** The firmware runs the rear-right wheel in
  single-channel counting mode by default (`rrSingleChannel = true`,
  `firmware/arduino_mecanum/mecanum_encoder_control.ino:191`), inferring direction from the
  last commanded PWM sign. It loses accuracy around direction reversals. It competed like
  this. Details and the pin-documentation contradiction are in
  [`docs/wiring-and-firmware.md`](docs/wiring-and-firmware.md#4-the-rear-right-encoder-a-pin).
- **Position-move tolerance was relaxed three times** (0.035 → 0.08 → 0.20 → 0.30 rad) because
  static friction chatter made tight tolerances time out under load. At 0.30 rad the residual
  wheel error is about 11.7 mm, against a grasp lateral tolerance of ±55 mm. The trade was
  accuracy we did not need for time we did.
- **In Final 1 the gripper stopped answering.** The bridge process stayed alive; the OpenRB just went quiet, and by the rule we had chosen the night before — only an active `empty` aborts a grasp — the robot carried an unconfirmed (empty) hand to the box. The crash-and-no-restart failure is a different one, from 05:12 that morning, and it was fixed before the finals. The robot reached the object and could not close
  on it; that match would have scored 90. Gripper-side software failure is visible as the
  hand letting go rather than freezing, by design — see
  [`docs/gripper-and-mast.md`](docs/gripper-and-mast.md#14-the-3-second-watchdog-is-a-dead-man-switch).
- **In Final 2 the 3-minute timeout hit** while grasping the last object.

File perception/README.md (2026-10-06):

# Part 2 — Object Detection

The robot has to answer two questions about every object in a 4 m × 4 m arena, in under
three minutes: **what shape is it**, and if it is a cube, **which fruit is printed on it**.

It answers them with a two-stage segmentation pipeline that was trained on
**zero hand-labelled images** — true right up to the qualifiers. Both finals then ran a face weight fine-tuned overnight on photographs of the real arena objects, relabelled by eye. Every other weight that ran in competition was trained on
BlenderProc-rendered synthetic scenes. How that data was made — and the three ways it
failed before it worked — is in [`docs/synthetic-data-experiments.md`](docs/synthetic-data-experiments.md).

---

## The pipeline in one picture

```mermaid
flowchart TD
    A["2× RealSense D435/D435I<br/>upper + lower, on a lifting mast"] --> B["Homography stitch<br/>near → top, one 3×3 matrix A"]
    B --> C["<b>Stage A1</b> — YOLO26s-seg, imgsz 896<br/>cube_like_object / octahedron /<br/>dodecahedron / icosahedron"]
    C -->|"polyhedron"| G
    C -->|"cube_like_object"| D["Crop: box + 0.18·max(w,h) pad"]
    D --> E["<b>Stage 2</b> — face seg, YOLO26s-seg<br/><b>imgsz 224, BGR</b>, ALL crops in ONE predict()<br/>apple / orange / banana / pineapple / plain"]
    E --> F["Face vote — a fruit face at conf ≥ 0.30<br/>outvotes a plain face"]
    F --> G["Depth back-projection in the <i>original</i><br/>camera frame → robot frame → map"]
    G --> H["Snap to the nearest of 42 grid points<br/>(50 cm pitch)"]
    H --> I["Per-cell K-vote → final identity + action"]
```

Non-cube polyhedra short-circuit after A1 and never enter the face stage. Only the
cube-like objects pay for the second model, and all of a frame's cube crops are paid for
in a single batched forward.

---

<p align="center">
  A1 shape detections and face identities drawn on a stitched arena frame during the centre scan, with a zoomed panel showing the per-detection labels
</p>
<p align="center"><em>Shot 11 of the twelve-frame centre scan, straight off the robot during Final 1
(10 detections, all 10 voted). Left: the stitched frame with A1 boxes. Right: the boxed region
enlarged, where each label reads <code>class · confidence · range · snapped cell</code> and the red
dot is the contact pixel the range was measured at.
<a href="../media/perception/scan.mp4">Full twelve-shot scan clip</a>.</em></p>

## What it was trained on, and what it actually sees

Left: what the model learned from. Right: what it was then asked to read on the arena floor.
The distance between those two pictures is most of this project.

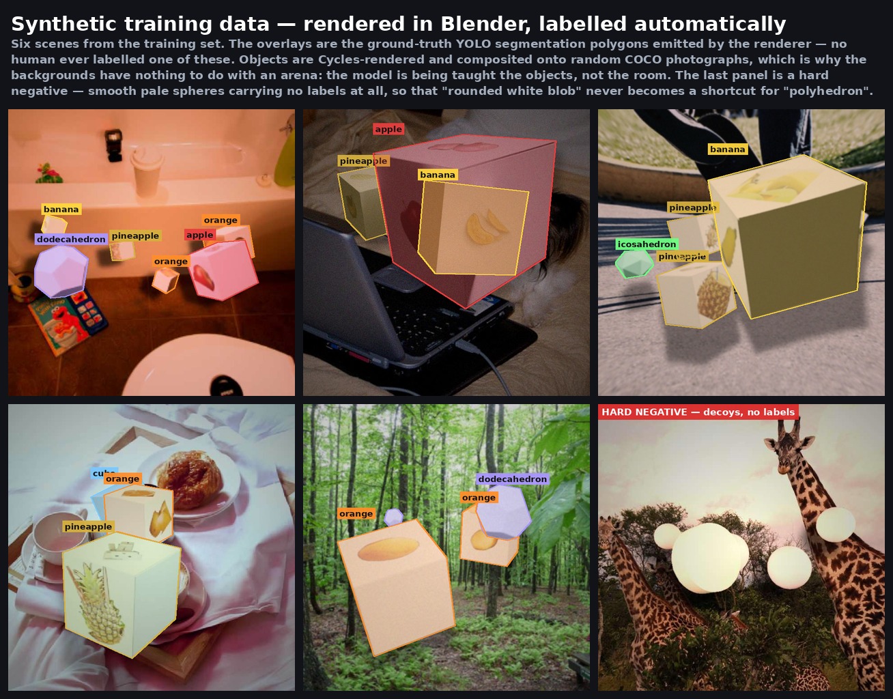
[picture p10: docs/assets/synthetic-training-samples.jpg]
Synthetic training scenes with ground-truth segmentation overlays


Rendered in Blender and labelled by the renderer — the polygons above are ground truth, not
predictions. Backgrounds are random COCO photographs on purpose: the model is being taught
the objects, not the room. The last panel carries **no labels at all**; roughly a fifth of
the training set is decoys like it, because every real object is a pale convex solid and
"pale convex blob ⇒ polyhedron" is a shortcut that would score well in validation and fail
in the arena.

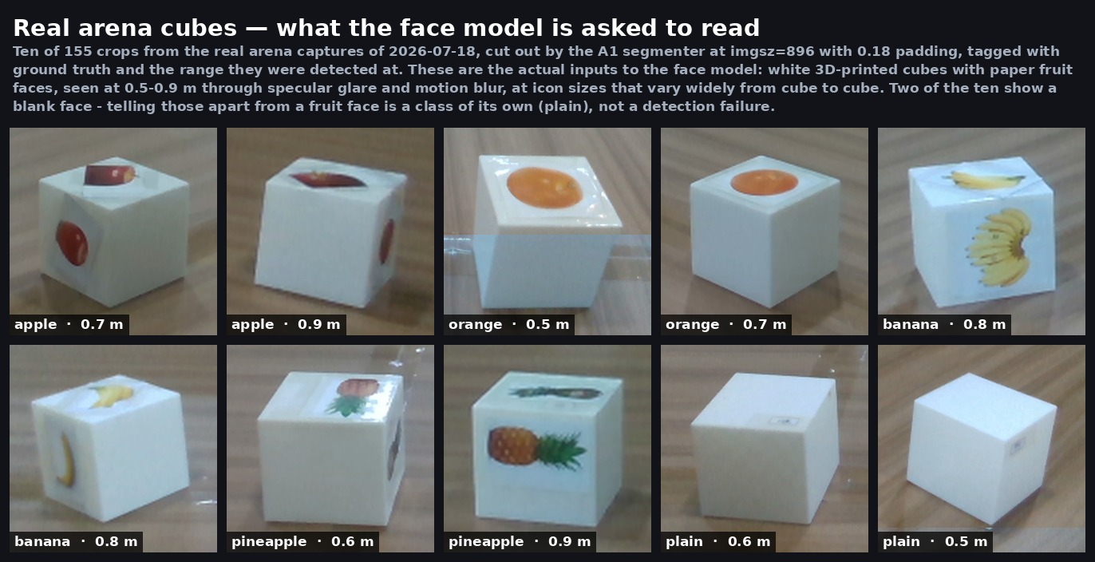
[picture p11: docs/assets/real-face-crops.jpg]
Real arena cube crops tagged with ground truth and range


The real thing: white 3D-printed cubes with paper fruit faces, cut out by A1 at 0.5–0.9 m,
through glare and motion blur, at icon sizes that vary a great deal between cubes. Two of
the ten show a blank face — `plain` is a class, not a miss. Recognising the *small*-icon end
of that range turned out to be a cliff rather than a slope, which is
[honest result 3](docs/synthetic-data-experiments.md#9-honest-result-3--the-recognition-cliff).

Both figures were made from the render sets and a real arena capture; the sources are the
datasets in section 10 of [`docs/synthetic-data-experiments.md`](docs/synthetic-data-experiments.md).

---

## Two runtime contracts that are not negotiable

Both were found the hard way, in the field, and both silently degrade accuracy rather
than raising an error.

| Contract | What happens if you break it |
|---|---|
| The face model **must** run at `imgsz=224` | Passing `imgsz=640` collapses face confidence from ~0.9 to 0.1–0.4 and the fruit labels start flipping. 224 is the training size; omitting `imgsz` entirely is also safe because Ultralytics reads it from the checkpoint. A1 is the opposite — it was trained at 640 and runs at 896 on the tall stitched frame. |
| The face model **must** receive **BGR** numpy arrays | Ultralytics' numpy path follows the `cv2.imread` convention. Feeding a PIL-read RGB array flips `orange ↔ plain` and `apple ↔ pineapple` (measured, not theorised). If you read with PIL, convert: `arr[:, :, ::-1]`. |

And one performance contract: **batch every crop of a frame into one `predict()` call.**
Measured on an RTX 5080, 5 crops: **10.9 ms batched vs 42.2 ms looped — 3.86×.**

These three rules cost a full day of debugging in July 2026. They also reversed an earlier
conclusion: a size-based "cube is too far, skip the face model" gate had looked essential,
but once the `imgsz`/BGR bugs were fixed the noise it was suppressing disappeared —
`cube_like_unresolved` detections went from 69 to 4 at the same threshold, and raising the
gate simply threw away good identifications. See [`docs/pipeline.md`](docs/pipeline.md) §3.

---

## What ships here

| Role | File | Architecture | Size | sha256 (first 8) |
|---|---|---|---:|---|
| A1 shape segmentation | `perception/models/a1_objectseg/best.pt` | YOLO26s-seg, 4 classes | 23,371,293 B | `08ffa8c4` |
| Face identity | `perception/models/unified_face/best.pt` | YOLO26s-seg, 5 classes, imgsz 224 | 23,291,542 B | `3d2d4dba` |
| apple↔orange verifier | `perception/models/verifiers/pair_apple_orange_v2.onnx` | MobileNetV3-Small 128 px | 6,089,237 B | `8dbca32c` |
| banana↔pineapple verifier | `perception/models/verifiers/pair_banana_pineapple_v2.onnx` | MobileNetV3-Small 128 px | 6,089,237 B | `630114ef` |

Face class order is fixed and index-dependent downstream: **0 apple, 1 orange, 2 banana,
3 pineapple, 4 plain.** Do not reorder.

One naming caveat worth knowing before you load anything: the file called
`pair_banana_pineapple_v2.onnx` is in fact the **v2_1** weight — the one retrained after a
real banana-*bunch* face flipped to pineapple at 0.758 in the field. The hash `630114ef`
matches `pair_banana_pineapple_v2_1`, not `v2`. `PairVerifier` prefers the `v2_1` name and
falls back to `v2`, and accepts either the flat `verifiers/<name>.onnx` layout used here or
the original `<name>/weights/best.onnx` training-tree layout
(`perception/fieldlib.py:405`–`423`).

Code:

- `perception/fieldlib.py` — the shared contract. `Stitcher` (exact-inverse homography),
  `PairVerifier`, `face_vote`, the six camera mounts, the model paths and every runtime
  constant (`perception/fieldlib.py:65`–`74`).
- `perception/geometry.py` — pure-math floor-plane back-projection and grasp alignment,
  no ROS, so it runs identically on the robot and in simulation.
- `perception/tools/` — the stitch calibrator, the venue photometry sweep, the live view.
- `perception/training/` — the training entry points, including
  `train_face_ft.py`, the 2026-07-24 real-photo fine-tune written the night before the
  finals.
- `perception/eval/face_model_compare.py` — the cached-crop A/B scorer that chose the
  shipped model.

---

## Three results we are publishing because they are negative

1. **The hue war.** Five face models scored 0.858–0.9024 mask mAP50-95 on synthetic
   validation and *all five lost* on the real robot. Root cause was triple: a renderer bug
   that clamped apple's hue *before* the per-channel BGR gains re-shifted it (50 % leakage
   into the orange band, 0.0 % after the fix), a realism asymmetry in which only apple had
   photographic cutout textures, and — worst — every render machine using the same default
   seed, so only ~22.8 k of 53.7 k scenes were unique and duplicates leaked across the
   train/val split. Details: [`docs/synthetic-data-experiments.md`](docs/synthetic-data-experiments.md) §7.

2. **`val = train` is not a number.** A1 read 0.9941 box mAP50 on a validation split that
   *was* its training set. A purpose-built held-out arena set (60 scenes, 573 objects) put
   it at 0.831 box mAP50 / 0.558 mask mAP50-95. A low-LR extra fine-tune gained +0.0002 on
   the fake validation and lost 1.5–2.5 pp on every held-out metric; it was rejected.

3. **The recognition cliff.** Recognition collapses when a printed icon covers roughly
   11–16 % of a cube face. Real arena icons cover 8–10 %. The training data only covered
   ~30 %. Enlarging failing crops recovered 25/30 of them — the model could read the icons,
   it had just never been shown small ones. A sparse-icon booster took recorded real-orange
   recognition from 65.1 % to 95.3 %.

The pair verifiers are a fourth: two measurements of them disagree, and both are published.
An offline 155-crop study says they help (+3 points); a robot-side 780-combination sweep on
175 real face patches says verifiers **off** is best (85.7 % vs 74.3 %). See
[`docs/pipeline.md`](docs/pipeline.md) §6.

---

## Documents

| Document | Contents |
|---|---|
| [`docs/pipeline.md`](docs/pipeline.md) | Stage-by-stage detail, every threshold with its reason, measured timings |
| [`docs/synthetic-data.md`](docs/synthetic-data.md) | Renderer design, visibility labels and metadata contract |
| [`docs/synthetic-data-reproduction.md`](docs/synthetic-data-reproduction.md) | Clean-checkout asset, render, split, export and training procedure |
| [`docs/synthetic-data-experiments.md`](docs/synthetic-data-experiments.md) | Historical experiments, failures, and dataset provenance |
| [`docs/models.md`](docs/models.md) | Weight standard, inference rules, Jetson `.engine`/`.pt` fallback, deprecation list |
| [`docs/stitching-and-calibration.md`](docs/stitching-and-calibration.md) | The exact-inverse stitch, resolution-independent calibration, photometry lock |
| [`docs/grid-voting.md`](docs/grid-voting.md) | 42-cell snapping and the asymmetric fruit vote |

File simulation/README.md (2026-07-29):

# Isaac Sim — kinematic surrogate

> **Policy.** This simulation is a **kinematic surrogate for perception and mission logic.**
> It is not a physics validator. Every claim this project makes about traction, roller slip,
> grasp force, motor current, PID behaviour or timing margin was measured on the real robot.
> The simulator's job is to let the *same* mission code, the *same* perception chain and the
> *same* ROS 2 topic contract run end-to-end against a known ground truth, thousands of times,
> without a charged battery.

The decision is recorded as [ADR-0004](../docs/adr/0004-simulation-is-kinematic-only.md).

---

## What we actually used it for

Mostly: **planning the match and spending the three minutes well.** The scoring
rules make this an optimisation problem before it is a robotics problem.

A perfect round is 7 objects — 4 from the first target set (40 points) and 3
from the second (60 points). Three minutes divided by seven is a **budget of
about 25 seconds per object**, scan and deposit included. And a wrong pickup is
penalised at *double* the object's value (−40 for a second-set mistake), so
"grab it if unsure" is negative expected value. Those two numbers drove almost
every behavioural decision in `mission/match_runner.py`.

The simulator is where those decisions were tried, because it runs the real
mission code against known ground truth as often as we like. Concretely, it is
where we worked out:

- **Where the time actually goes.** Every run writes a per-object phase
  breakdown — route / face / approach / grasp / carry — so a cycle that blew the
  25 s budget could be attributed rather than guessed at.
- **That rotation was the expensive thing.** Excess turning was collapsing the
  localiser, so cardinal snapping was replaced with a 4-axis
  minimum-residual alignment (±15°, 45° max) and short, final and highway legs
  stopped rotating at all.
- **That "settling" was costing whole seconds per move.** Relaxing the goal
  tolerance to 0.25 m, adding a 1.0 s stall early-exit, and skipping
  micro-rotations below 0.10 rad removed a deadband-parking → firmware-settling
  grind that had been eating ~8 s in a single reverse.
- **The route policy.** The arena is a 42-point grid on 50 cm spacing with 28
  points occupied; the gap between neighbours is 42 cm against a 40 cm robot, so
  cutting between columns is not survivable. The band below y = 100 cm is always
  empty, which makes it a free highway between the storage bin and the start
  zone. Approaching each column from below keeps the path behind the robot clear.
- **Target ordering and quotas** — first/second set quotas, fruit-first
  sequencing, and refusing non-target objects outright.

None of this needed physics. It needed the real state machine, a real map, real
detections and a clock — which is exactly what a kinematic surrogate provides,
at a rate no amount of battery-swapping on the real robot could match.

The honest caveat: **sim wall-clock timings are not the robot's timings.** Runs
come out roughly 2–3× slower. The *ratios and the ordering* transfer — which is
what the decisions above rested on — but the absolute seconds do not. Real
per-stage timings live in `docs/07-results-and-lessons.md`.

This is a limitation of the mover, not something inherent to kinematic
simulation, and it is worth fixing. Two causes, both in
`scripts/create_mecanum_competition_scene.py`:

- `move_speed_cap` is taken from the mission layer's `max_v`, but moves that
  don't specify one fall back to `MOVE_RELATIVE_MAX_LINEAR_MPS = 0.18` m/s,
  below the real firmware's 0.233 m/s default.
- More importantly, `_move_relative_twist()` is **pure proportional control**
  (`v = 5.0 × error`, clamped). Velocity decays to zero as the goal is
  approached, so every move ends in a long crawl to the 0.01 m tolerance. The
  real firmware runs a **trapezoidal profile** instead — accelerate at
  12.0 rad/s², cruise, decelerate — which covers the same distance far faster.

Porting the firmware's trapezoid into the sim mover, and taking the speed caps
from the robot's own configuration, is what would bring sim wall-clock into
agreement with the real robot without any post-hoc time scaling.

---

## What it is

`simulation/scripts/create_mecanum_competition_scene.py` composes the arena stage
(`simulation/usd/stadium_competition_grid42.usd`) with the mecanum robot URDF
(`hardware/cad/urdf/robot_mk3_mecanum_sim_80mm.urdf`) and then runs a ROS 2 bridge that
**mirrors the real robot's topic contract exactly** — same topic names, same JSON payload
vocabulary, same command semantics. It imports the robot's own
`robot_hardware.mecanum_control.MecanumKinematics`, so the sim exercises the identical
inverse/forward kinematics the firmware bridge runs.

The consequence that matters: the competition state machine
(`mission/match_runner.py`) drives the simulator and the real robot with **no code
branch and no sim flag**. If a run works in sim, the same bytes ran.

### The bridge contract

| Direction | Topic | Type / payload |
|---|---|---|
| sub | `/cmd_vel_direct` > `/cmd_vel` > `/cmd_vel_smoothed` > `/cmd_vel_nav` | `geometry_msgs/Twist`, 0.5 s staleness priority mux (same order as `cmd_vel_mux_node`) |
| sub | `/base/move_relative` | `std_msgs/String` JSON `{dx, dy, dyaw, max_v}` |
| sub | `/gripper/command`, `/lift/command` | `std_msgs/String` (`OPEN`/`CLOSE`/`SET_DEG`, `LIFT_TO_TOP`/`LIFT_TO_BOTTOM`/`LIFT_STATUS?`) |
| sub | `/safety/e_stop`, `/sim/lighting` | e-stop; runtime lighting hook `{key, fill, color}` |
| pub | `/odom/wheel` (+ `/chassis/odom`), `/joint_states`, `/motor/state` | odometry and wheel telemetry, `drive_type=mecanum` |
| pub | `/base/move_result` | JSON result for each relative move |
| pub | `/laser_scan` | re-stamped from the Isaac PhysX lidar |
| pub | `/imu/d435i` | synthetic BMI055 gyro/accel (noise density, bias, range from the datasheet) |
| pub | `/camera_19/{rgb,depth,camera_info}`, `/camera_54/{rgb,depth,camera_info}` | top and near cameras, **640×480** |
| pub | `/gripper/state`, `/gripper/grasp`, `/lift/state` | real bridge vocabulary, incl. `{"state": "held"\|"empty"\|"checking"\|"unknown"}` |
| pub | `/sim/ground_truth_pose`, `/sim/objects_state` | ground truth — sim only, never consumed by mission code |
| pub | `/clock`, TF `odom → base_link` | |

Both cameras ride a **runtime-animated camera mast**: `/lift/command` interpolates between
the four measured mount pairs (down/up × top/near), on wall time, with the same
~7 s raise / ~6 s lower durations as the real lift, and publishes `/lift/state` with the
real payload shape. Mounts are kept digit-identical with `perception/fieldlib.py`:

| mast | camera | forward (m) | height (m) | tilt (deg) |
|---|---|---|---|---|
| down | top | 0.198 | 0.3497 | 18.44 |
| down | near | 0.1874 | 0.3143 | 53.20 |
| up | top | 0.198 | 0.4986 | 19.39 |
| up | near | 0.1874 | 0.4600 | 53.24 |

Note that raising the mast is *not* a pure height offset — the top bracket sags by
+0.95 deg when extended. Modelling UP as "DOWN plus height" silently biases every
back-projected object range.

### The arena

`generate_competition_stadium_layout.py --layout grid42 --seed 14 --target-size-m 0.08
--random-yaw` places 28 objects (4 cubes × 4 polyhedra classes, 3 each of apple / orange /
banana / pineapple faces) on 28 of the 42 official 50 cm grid points, applies random yaw,
and enforces the arena's face rule (fruit on the front, top and back; blank on the left, right
and bottom).
It emits a JSON inventory that is the ground truth for every parity measurement, and
`logs`-free ground-truth text that `mission/match_runner.py --gt-file` reads directly.

---

## What it is good for

Concretely, these are things the surrogate found or proved that hardware time could not
have afforded:

- **Perception parity on a known layout.** `field_parity_analyze.py` replays the *real*
  recognition chain (stitch → A1 at imgsz 896 → 224 BGR crops → face vote → depth
  back-projection → 42-cell snap → cell vote) over sim captures. It does not reimplement
  the chain; it subclasses `E2ERunner` from `mission/match_runner.py` and calls the real
  `_process_shots_batch` / `_finalize_scan`. Single-source or it is not parity.
- **Mission-logic regression.** Full 3-minute runs against ground truth: scan → approach →
  measure → grasp → transport → place → retreat, with per-cycle timings and a
  GT-vs-detection confusion table.
- **Contract regression.** The 2026-07-20 field bug where the runner read
  `grasp_state` instead of `state` from `/gripper/grasp` is exactly the class of bug the
  surrogate catches, because the sim publishes the real key.
- **Negative-path verification.** The mis-identification guard (`verify_target`) was
  exercised on *both* branches in sim: agreement (apple 0.96 → grasp → store) and a
  confirmed contradiction (scan said apple, re-check said pineapple 0.58 → skip), which is
  what prevents a 2× mis-pick penalty.
- **Geometry and routing.** Street-router clearance, storage-zone pin layout, and the
  scan-saturation argument (28 of 28 cells covered in a 24 s spin scan) are pure geometry
  and transfer.
- **Photometry rehearsal.** Renderer lighting was swept until the sim cameras matched the
  measured arena band statistics, so the perception chain rehearses at field-equivalent
  brightness rather than studio brightness. See [docs/field-parity.md](docs/field-parity.md).

## What it is not good for

- **Anything involving contact.** Mecanum roller slip, wheel scale error, floor friction,
  gripper closing force, whether an icosahedron rolls out of the fingers. `--drive-mode
  physics` exists and articulates the four wheels with Kaya-style 45° passive rollers, but
  it was **never used as evidence**. At physics rates the real-time factor drops and CPU
  contention makes the localizer run under conditions the robot never sees, so a physics
  result is neither a pass nor a fail — it is a different experiment.
- **Grasp success.** Grasping in sim is a *cheat grip*: on `CLOSE` the nearest object inside
  a hard-coded zone (0.095–0.245 m ahead of base centre, |lateral| ≤ 0.06 m) is attached to
  the robot. A miss logs a diagnostic in the robot frame. This validates *aiming*, never
  *holding*. The real grasp check is sensorless and measured on hardware — settled finger
  gap 3.0–3.2° empty vs 14.1° holding an icosahedron, threshold 8.0°.
- **Timing budgets.** Sim `move_relative` is a P-controller capped at 0.18 m/s
  (`MOVE_RELATIVE_MAX_LINEAR_MPS`), while the real firmware runs its own trapezoidal
  profile. Measured sim moves ran a consistent **2.4–2.9× slower** than the field. The
  instrumentation (`move_stats`) is the transferable part; the wall-clock numbers are not.
- **Face identity confidence.** Sim cube textures are cleaner than printed paper under
  arena light, so face-level accuracy in sim is *optimistic*. Trust the surrogate to the
  A1 four-class level (cube / octahedron / dodecahedron / icosahedron); do not read sim
  fruit accuracy as a field prediction. This is stated again, with numbers, in the parity
  study.

---

## Running it

Requires Isaac Sim 5.1 with its bundled ROS 2 bridge. Three terminals.

```bash
# T1 — the scene (headless, kinematic, mast down, 4 h session)
scripts/run_isaac_mecanum_scene.sh --headless --drive-mode kinematic --mast down --run-seconds 14400

# T2 — the real arena localizer, unmodified
source /opt/ros/humble/setup.bash && source install/setup.bash
ros2 run arena_lightweight_control arena_control_node --ros-args \
  -p controller_type:=mecanum -p localization_mode:=wall_range \
  -p localization_reseed_yaw_step_rad:=0.12 -p localization_reseed_xy_step_m:=0.24 \
  -p imu_topic:=/imu/d435i

# T3 — re-apply the low-light preset (it is not persisted in the USD), then run a match
ros2 topic pub --once /sim/lighting std_msgs/msg/String \
  "{data: '{\"key\": 331.875, \"fill\": 232.3125}'}"
python3 mission/match_runner.py --gt-file <ground-truth.txt> --max-objects 3 \
  --pair off --speed-profile normal --votes-k 1 --fruit-k 1 --yes
```

Two operational gotchas, both learned the hard way:

1. `match_runner.py` needs `rclpy` **and** torch/ultralytics in the *same* interpreter.
   A ROS-sourced system python usually has the first and not the second; use an
   environment that has both.
2. Before re-running a match, the robot must be within 0.35 m of START
   (1.8, −1.8, 90°) — that is the seed gate. Sessions where the robot was manually
   teleported and reset repeatedly accumulated pose residue and produced a run of
   all-failed grasps that had nothing to do with the code under test. If a run looks
   inexplicably bad, reboot the simulator before believing it.

Perception-only parity (no mission run):

```bash
python3 simulation/scripts/street_dataset_sim_capture.py   # drives scan points, saves raw pairs + depth + poses
python3 simulation/scripts/field_parity_analyze.py --capture-dir <dir> --mast up --out <dir>
```

`street_dataset_sim_capture.py` always saves the **raw top/near pair** alongside the
stitched frame, exactly as the field capture tools do — a stitched-only archive cannot be
re-diagnosed.

---

## Files

| Path | Role |
|---|---|
| `scripts/create_mecanum_competition_scene.py` | Scene composer + ROS 2 bridge. The whole surrogate. |
| `scripts/generate_competition_stadium_layout.py` | Arena generator: official cm→map transform, 42 grid points, face rule, JSON inventory. |
| `scripts/street_dataset_sim_capture.py` | Multi-point rotate-and-shoot capture (raw pairs + depth + localizer pose + GT pose per shot). |
| `scripts/field_parity_analyze.py` | Offline replay of the real recognition chain over sim captures. |
| `scripts/lowlight_lighting_sweep.py` | Drives sim lighting to the measured arena band statistics; writes the preset. |
| `scripts/mecanum_motion_selftest.py` | Asserts forward/strafe/rotate signs against ground truth. Exits 0/1 with a JSON verdict. |
| `usd/stadium.usd` | Base stage: 4×4 m floor, 30 cm walls, source object prims. |
| `usd/stadium_competition_grid42.usd` | The arena used in every 2026-07 rehearsal (seed 14, 28 objects). |

`create_mecanum_competition_scene.py` imports `create_mobile_manipulator_scene.py` as a
library for camera specs, publisher wiring and collision-primitive rendering; both must be
in the same directory.

---

## Renderer settings

Three Isaac render defaults invalidate small-object perception experiments, and all three
produce plausible-looking output while doing it. Set them in the Isaac process before any
capture:

```python
carb.settings.get_settings().set("/rtx/post/histogram/enabled", False)  # no auto-exposure
carb.settings.get_settings().set("/rtx/post/tonemap/op", 1)             # linear, no filmic shoulder
carb.settings.get_settings().set("/rtx/post/dlss/execMode", 3)          # DLAA: native res, no upscale
```

With auto-exposure on, a lighting sweep converges on nothing; with DLSS upscaling on, a
640×480 camera renders internally at 320×240 and top-camera detection range collapses from
3.0 m to 1.9 m. The measurements behind each value are in
[docs/field-parity.md](docs/field-parity.md#2-the-three-renderer-traps).

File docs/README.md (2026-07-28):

# Documentation index

Every document in this repository, with one line on what it is for. Start at
[`../README.md`](../README.md) if you have not read it; start at
[`07-results-and-lessons.md`](07-results-and-lessons.md) if you only read one page.

---

## Numbered guides — read in order, or by need

| Document | Purpose |
|---|---|
| [`01-competition-and-rules.md`](01-competition-and-rules.md) | The constraints every design decision answers to: arena, 42-point grid, both object sets, the scoring table with its 2× mispick penalty, and a rule → code → file map. |
| [`02-architecture.md`](02-architecture.md) | The four layers (firmware / device bridges / arena control / mission script), why the boundaries are where they are, the match state machine, and why there are no custom ROS messages. |
| [`03-ros2-interfaces.md`](03-ros2-interfaces.md) | The exhaustive sensor → bridge → actuator graph: every node, topic, message type, QoS profile, JSON payload schema and serial line. Written from the code. |
| [`04-getting-started.md`](04-getting-started.md) | Install, build, fetch weights, run the tests, launch the stack, run a match — plus §10, the four classes of artefact that are ours and do not transfer. |
| [`05-field-runbook.md`](05-field-runbook.md) | Competition-day procedure as operated: two-phase bringup, health checks, pose seeding, the match invocation, symptom → action, shutdown. |
| [`06-troubleshooting.md`](06-troubleshooting.md) | Symptom → first hypothesis → action, and the traps that cost the most time (wrong `imgsz`, RGB/BGR, duplicate bridges, a lost mast home, silently no-op speed profiles). |
| [`07-results-and-lessons.md`](07-results-and-lessons.md) | The record: the score, every measured number with where it was measured, the three competition failures, four negative results, ten transferable lessons. |
| [`08-reproducibility.md`](08-reproducibility.md) | What can and cannot be reproduced from this repository, and what has to be re-measured on your own robot and at your own venue. |
| [`CREDITS.md`](CREDITS.md) | The seven team members, their GitHub accounts, how the work split, and the AI tooling disclosure. |

## Architecture decision records

| Record | Decision |
|---|---|
| [`adr/README.md`](adr/README.md) | Index and format note — every record ends in costs, including the ones paid publicly. |
| [`adr/0001-drop-nav2.md`](adr/0001-drop-nav2.md) | Drop Nav2 for a hand-written wall-range localiser, and what that gives up. |
| [`adr/0002-json-over-std-msgs-instead-of-custom-messages.md`](adr/0002-json-over-std-msgs-instead-of-custom-messages.md) | JSON on `std_msgs/String` instead of an interface package — and the misread key that made every successful grasp score as a failure. |
| [`adr/0003-firmware-owns-motion-primitives.md`](adr/0003-firmware-owns-motion-primitives.md) | Wheel PID and synchronised trapezoidal moves live in the Arduino, not the host. |
| [`adr/0004-simulation-is-kinematic-only.md`](adr/0004-simulation-is-kinematic-only.md) | Isaac Sim is a perception and mission-logic surrogate; physics was validated on the robot. |
| [`adr/0005-synthetic-only-training-data.md`](adr/0005-synthetic-only-training-data.md) | Zero hand-labelled images. It survived a rule change four days out and lost the qualifiers to an under-ripe apple. |

---

## Subsystem documentation

### Hardware

| Document | Purpose |
|---|---|
| [`../hardware/README.md`](../hardware/README.md) | What the robot is, the three-microcontroller rules, the rebuild order, and which constants are *fitted* rather than physical. |
| [`../hardware/docs/bom.md`](../hardware/docs/bom.md) | Bill of materials, quantities and substitution notes. |
| [`../hardware/docs/wiring-and-firmware.md`](../hardware/docs/wiring-and-firmware.md) | Pin map, motor drivers, the complete serial grammar of both boards, the PID cascade, and five serial-layer bugs fixed in the field. |
| [`../hardware/docs/gripper-and-mast.md`](../hardware/docs/gripper-and-mast.md) | Sensorless grasp detection by settled position gap, limit-switch-free mast homing, and the one-process-owns-the-tty rule. |
| [`../hardware/bringup_tools/README.md`](../hardware/bringup_tools/README.md) | The numbered 00..53 bring-up chain (original Korean). |
| [`../hardware/firmware/arduino_mecanum/README.md`](../hardware/firmware/arduino_mecanum/README.md) | Original Korean firmware notes; its pin table is stale — see `wiring-and-firmware.md`. |

### Perception

| Document | Purpose |
|---|---|
| [`../perception/README.md`](../perception/README.md) | The two-stage pipeline in one picture, the two non-negotiable runtime contracts, what ships, and three negative results. |
| [`../perception/docs/pipeline.md`](../perception/docs/pipeline.md) | Stage by stage, every threshold with the observation that set it, and measured timings. |
| [`../perception/docs/synthetic-data.md`](../perception/docs/synthetic-data.md) | How the training set was rendered in Blender, and the three failures that shaped it — including the shared-seed leak. |
| [`../perception/docs/models.md`](../perception/docs/models.md) | Weight standard, inference rules, the Jetson `.engine`/`.pt` fallback, and the deprecation list. |
| [`../perception/docs/stitching-and-calibration.md`](../perception/docs/stitching-and-calibration.md) | The exact-inverse dual-camera stitch, resolution-independent calibration, and the venue photometry lock. |
| [`../perception/docs/grid-voting.md`](../perception/docs/grid-voting.md) | Snapping detections to the 42-cell grid and the asymmetric fruit vote. |

### Navigation

| Document | Purpose |
|---|---|
| [`../navigation/README.md`](../navigation/README.md) | Why Nav2 was deleted, the measurement that decided it, the before/after component table, and what you give up. |
| [`../navigation/docs/localization.md`](../navigation/docs/localization.md) | The wall-range matcher, the IMU yaw prior, the square arena's 4-fold symmetry, and latency handling. |
| [`../navigation/docs/control-and-routing.md`](../navigation/docs/control-and-routing.md) | Goal latch, mecanum controller, speed profiles, and the street router. |

### Mission and simulation

| Document | Purpose |
|---|---|
| [`../mission/README.md`](../mission/README.md) | How to run a match, the full CLI reference, what each stage does, the outputs, and the exit codes. |
| [`../mission/docs/match-strategy.md`](../mission/docs/match-strategy.md) | Why the scan happens where it does, why ranging comes from depth, the storage geometry, and what we would change. |
| [`../simulation/README.md`](../simulation/README.md) | The Isaac Sim kinematic surrogate: its topic contract, what it is good for, and what it must never be trusted for. |
| [`../simulation/docs/field-parity.md`](../simulation/docs/field-parity.md) | The sim-to-field parity study, including the three renderer traps that silently invalidate results. |

### Repository meta

| Document | Purpose |
|---|---|
| [`../CONTRIBUTING.md`](../CONTRIBUTING.md) | How to build, how to test, the translate-never-delete comment policy, and English-only for new documentation. |
| [`../NOTICE`](../NOTICE) | Third-party components, their licences, and what is deliberately not redistributed. |
| [`../CITATION.cff`](../CITATION.cff) | Citation metadata. |
| [`../media/README.md`](../media/README.md) | What team-supplied media goes where; each subdirectory names its expected files. |

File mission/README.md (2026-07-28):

# Mission — the match runner

`mission/match_runner.py` is the program that plays a match. It is **not** a ROS node: it is a
single standalone `rclpy` client (2,508 lines) that drives the three subsystems — hardware bridges,
perception, and the Nav2-free arena controller — purely over topics, using the shared contract
library `perception/fieldlib.py`.

Everything the robot did on competition day went through this one file, launched by `scripts/run_match_day.sh`.

```
STARTUP → SEED → MAST_UP → GOTO_CENTER → SCAN (12 × 30° CW) → MAST_DOWN
        → COLLECT { ROUTE → FACE → APPROACH → GRASP → CARRY } × N → REPORT
```

Why a client script and not a node: it needs to block, prompt an operator, run YOLO in-process, and
write a self-scoring report. Nothing in it needs to be a lifecycle-managed node, and keeping it out
of the launch graph meant we could edit and rerun the match logic between two runs on the field
without rebuilding a colcon workspace.

> The shipped script logs in Korean and its module docstring still refers to the original repository
> layout (`scripts/dev/field_ops/e2e_match_test.py`). The commands below use this repository's paths.

---

## 1. Running a match

Two commands, in this order, on the Jetson.

```bash
source /opt/ros/humble/setup.bash && source install/setup.bash

# 1. bring the stack up, health-check it, seed the START pose
python3 -u mission/field_autopilot.py up

# 2. play the match (Set 1 target = icosahedron, Set 2 target = apple)
python3 mission/match_runner.py --yes --target-shape icosahedron --target-fruit apple
```

`field_autopilot.py up` runs the operator checklist (battery on / robot in the start zone facing
north / mast at the bottom / gripper clear / arena clear), launches all bridges (killing stale
duplicates first — two motor bridges on one Arduino tty corrupt commands), checks topic health, and
seeds the start pose. Exit 0 = go, exit 2 = a required component is missing. Its other verbs are
`check` (diagnose only), `record` (dataset capture: raw top/near RGB + depth pairs, YOLO debug
overlays, a rosbag and per-frame pose), `teleop` (keyboard driving), `down` (stop everything and
report leftovers). `--offline` makes `up`/`check` self-diagnose without ROS.

`match_runner.py` re-does its own health check and checklist, so it is safe to run it directly.

Other useful invocations:

```bash
# rehearsal with a known ground-truth layout, 3 objects, no placement
python3 mission/match_runner.py --gt-text "apple:150,200;plain:250,300" --max-objects 3 --no-place

# reuse a scan you already have (mast stays down)
python3 mission/match_runner.py --skip-scan --map-file logs/field_ops/<ts>_e2e/grid_map.json

# skip the scan entirely and use the ground-truth layout as the map (approach/place only)
python3 mission/match_runner.py --gt-map --gt-file gt.txt

# no ROS, no ultralytics — parser / GT / router / candidate-filter self-test
python3 mission/match_runner.py --offline
```

`gt_layout_generator.html` (open it in a browser) rolls a rule-legal 28-of-42 layout from a seed and
emits the matching `--gt-text ... --target-shape ... --target-fruit ...` command line, so a rehearsal
layout is reproducible and you never type 28 objects by hand.

---

## 2. CLI reference

Every flag, with its default.

### Target policy (competition mode)

| Flag | Default | Meaning |
|---|---|---|
| `--target-shape {cube,plain,octahedron,dodecahedron,icosahedron}` | none | Set 1 target shape, announced on the morning of the match. 10 pts each. `cube` is an alias for `plain` — a cube with no fruit face has perceptual identity `plain`. |
| `--target-fruit {apple,banana,orange,pineapple}` | none | Set 2 target fruit, announced right before the match. 20 pts each. |
| `--shape-quota N` | `4` | How many Set 1 targets are in the arena (rulebook default). |
| `--fruit-quota N` | `3` | How many Set 2 targets are in the arena (rulebook default). |
| `--order {nearest,fruit-first,shape-first}` | `nearest` | Collection order. `fruit-first` prefers the 20-pt set while any remain. |
| `--target-class CLS` | none | **Rehearsal only.** Prefer cells of one class, falling back to nearest-any if none are confirmed. Mutually exclusive with `--target-shape` / `--target-fruit`, which are strict (no non-target fallback ever). |
| `--max-objects N` | target mode: `sum(quotas) + 5` (= 12); otherwise `3` | Hard cap on collection cycles. The loop also exits early once every quota is filled. |

### Ground truth and map

| Flag | Default | Meaning |
|---|---|---|
| `--gt-text "cls:x,y;..."` | `""` | Object layout in official cm (grid points only: x ∈ 50…350, y ∈ 100…350, 50 cm pitch). Used for the scan-vs-truth confusion table. |
| `--gt-file PATH` | `""` | Same, from a file. |
| `--gt-map` | off | Drive to the scan point but skip the scan; use the GT layout as the map. Tests approach + placement only. Mast deliberately stays **down** (approach ranging uses the near camera). |
| `--skip-scan` | off | Skip scan and travel; load a previous map. Requires `--map-file`. |
| `--map-file PATH` | `""` | `grid_map.json` from an earlier run. |
| `--mast-up` | off | In `--gt-map` mode, raise the mast anyway (lift hardware check only). |

### Scan

| Flag | Default | Meaning |
|---|---|---|
| `--scan-shots N` | `8` | Steps the 360° spin is divided into. |
| `--scan-mode {step,continuous}` | `step` | `step` stops at each heading; `continuous` shoots while rotating. |
| `--scan-mast {up,mid}` | `up` | Mast height for the scan. `mid` needs firmware `LIFT_TO_MID` **and** a `perception/calibration/stitch/mid.json`; the runner refuses to start otherwise. |
| `--scan-settle S` | `0.35` | Post-rotation settle before the shot (motion-blur guard; was 0.6 s until 2026-07-20). |
| `--votes-k N` | `3` | Votes needed to confirm a cell (`fieldlib.CELL_VOTES_MIN`). |
| `--fruit-k N` | `2` | Strong fruit-face votes needed to confirm a fruit identity (`fieldlib.CELL_FRUIT_K`). |
| `--pair {on,off}` | `on` | Binary pair re-verifiers (apple-vs-orange, banana-vs-pineapple) as a second opinion. Auto-disables if the ONNX files are missing. |

### Approach, grasp, placement

| Flag | Default | Meaning |
|---|---|---|
| `--range-mode {depth,ground}` | `depth` | How the object's range is computed. `depth` = median depth at the contact pixel; `ground` = back-project the silhouette's lowest pixel onto the floor plane. `ground` was the default until 2026-07-21 and is systematically long on round shapes (see `mission/docs/match-strategy.md`). |
| `--no-place` | off | Grasp only, then put the object back and move on. |
| `--place-anyway` | off | Carry and place even if the grasp feedback never says `held`. Skips the re-grasp retry when feedback is simply absent, so a genuinely gripped object is not dropped by an `OPEN`. |
| `--release-ticks T` | `450` (≈ 39.6°) | Gripper opening at drop-off, **relative to the current finger position**. A full open hits the storage wall, and an absolute angle is meaningless while the fingers are stopped on an object. XC330 = 4096 ticks / 360°. |
| `--no-place-settle` | off | Skip pose stabilisation on the return path (0.2 m back-off, 0.2 s goal settle). Removing it was tried on 2026-07-20 and rolled back; default is on. |

### Speed

| Flag | Default | Meaning |
|---|---|---|
| `--speed-profile {safe,normal,fast}` | `normal` | Three speeds at once — cruise / approach / place in m/s: `safe` 0.5 / 0.4 / 0.3, `normal` 0.8 / 0.6 / 0.4, `fast` 0.95 / 0.7 / 0.45. `fast` is ≈95 % of the measured hardware limit (~1.0 m/s). |
| `--max-v V` | none | Override cruise only, ignoring the profile. |

Cruise speed is pushed to the arena node with `ros2 param set /arena_control_node max_linear_mps`
at startup. Before that was added (2026-07-20) the profiles silently did nothing on goal-following
drives, because `do_goto` uses the arena node's closed-loop controller and never carried a speed.

### Operations and debugging

| Flag | Default | Meaning |
|---|---|---|
| `--yes` | off | Skip all operator prompts (checklist, mast confirmation, gripper-missing confirmation). Use for a real match. |
| `--launch-stack` | off | Start the arena stack via `BridgeManager` and retry the health check up to 12 times while it boots. |
| `--dry-run` | off | Log motion/gripper/lift commands instead of sending them. Still scans and infers if frames are available; synthesises cell votes from GT if not. |
| `--offline` | off | ROS-free, ultralytics-free self-test; exits immediately after. |

Argument errors exit with **2** (argparse default), which collides with the health-gap exit code —
read the message, not just the code.

---

## 3. What each stage does

Timings below are real-robot measurements where stated; where a number comes from an Isaac Sim
kinematic run it is labelled as such, because the simulator's drive dynamics are not the robot's.

| Stage | What happens | Timing |
|---|---|---|
| **STARTUP** | GT prompt → optional stack launch → `rclpy` init → duplicate motor-bridge cleanup → topic health check (8 s listen) → operator checklist. A background thread starts loading YOLO the moment the program starts. | model preload ≈10 s (import + weights + CUDA warm-up), fully overlapped with the above |
| **SEED** | Publishes the start pose `(1.8, −1.8, +90°)` map = official `(380, 20) cm`, facing +y, then polls arena status every 0.25 s for up to 3 s and requires a localisation latency < 150 ms. Exits **4** if the localiser never locks. | ~1.5 s |
| **MAST_UP** | `LIFT_TO_TOP` through `/lift/command` (never the tty directly — opening the tty resets the board via DTR and loses the lift home). Issued non-blocking so the climb overlaps driving. Completion is `MOVING=0` **or** an elapsed-time bound, whichever comes first. | measured: up ≈7 s, down ≈6 s; mid ≈4 s is an estimate (half the stroke), never measured |
| **GOTO_CENTER** | One diagonal, then one street leg (`street_diag`). The diagonal is a single holonomic move from the start pose to `(0.25, −1.40)`, the highway line, capped at 0.6 m/s. It stops there rather than running straight to the pre-shot at `(0.25, −1.25)`: crossing the x = +0.5 m object row 15 cm further north leaves only ~3 cm between the north-facing gripper tip and the southernmost silhouette, so the last 15 cm is a street move instead. Then the pre-shot, then leg 2 north along x = +0.25 m to the scan point `(0.25, 0.25)` map = official `(225, 225) cm`. The mast raise overlaps all of it. The two-leg right-angle route (`street_L`) survives only as the fallback when the pre-shot is off. | **10.1–10.7 s** across the four competition matches (stage total, includes the pre-shot capture) |
| **SCAN** | Releases the arena goal, then 12 shots at 30° CW steps with a 0.5 s settle each. Immediately after the last capture the mast-down command is issued (non-blocking) so the ~6 s descent overlaps inference. All shots are then stitched and inferred **in batches** — A1 in chunks of 8, face crops in chunks of 32 — because a single 65-image batch exhausted the Orin Nano's 8 GB unified memory (NvMap error 12 → CUDA allocator assert). Every detection is back-projected and voted onto the 42-cell grid. | **20.6–27.0 s** across the four competition matches (12 shots, stage total including the batched inference); per-run batch stage timings are in `report.scan.batch_timing` |
| **COLLECT** ×N | Per cycle: **ROUTE** (north-locked street loop to a mini-goal one grid diagonal south-east of the object) → **FACE** (±45° to the object) → **APPROACH** (sync mast-down, open gripper, measure with up to 6 retries, optional defensive hop, re-verify the class, one relative move) → **GRASP** (`CLOSE`, wait for `state == "held"`; retry only if the bridge actively reports `empty`, carry on if it says nothing) → **CARRY** (rewind the approach, street south, **drift** to staging `(−1.40, −1.40)` while turning to −135°, placement gate, advance into the pin with a 2.5 cm push, release, retreat 0.35 m, re-close). | approach ≈2.5–2.8 s normally, 3.4–4.9 s when all 6 measurement attempts fail (log analysis, 2026-07-21) |
| **REPORT** | Joins the background image-saving thread, scores the run against the rulebook, prints the summary, writes `report.json`. Runs in a `finally`, so a crash or Ctrl-C still produces a report. | — |

<p align="center">
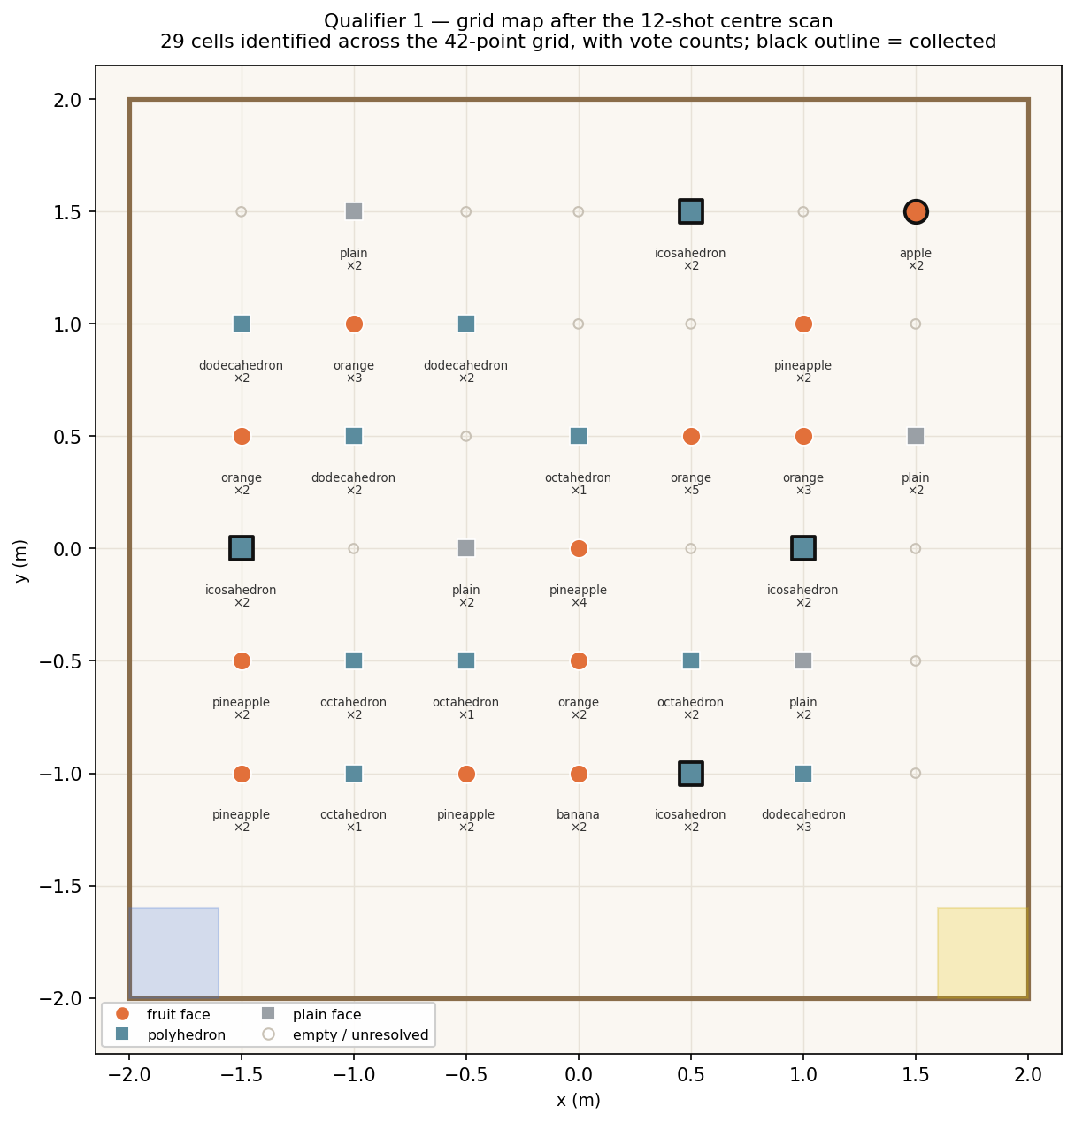
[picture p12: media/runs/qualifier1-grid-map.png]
The 42-point grid after Qualifier 1's centre scan, each identified cell labelled with its class and vote count
  
</p>
<p align="center"><em>What SCAN hands to COLLECT: one identity and one vote count per cell, from a
single spin at the arena centre. The five cells outlined in black are the ones this match went on to
collect — chosen by expected value, not by distance.</em></p>

Two behaviours worth calling out because they cost real seconds:

* **Latency hiding is deliberate.** YOLO loads during GT entry and driving; the mast rises during
  highway leg 2; the mast descends during batch inference; scan PNGs are written on a background
  thread instead of inside the inference path.
* **Unspecified `max_v` is a trap.** A `-0.2 m` reverse once took ~8 s against a 1.1 s prediction.
  Cause: `move_relative` without `max_v` falls back to the firmware's `position_max_rad_s = 6.0`,
  i.e. **0.233 m/s**, and the firmware deadline (`profile × 2 + 5 s`) then timed out. Every relative
  move now passes an explicit speed, and `do_move` records elapsed-vs-expected into
  `report.move_stats` so this class of stall shows up without log archaeology.

Three perception details the SCAN row depends on: A1 runs on the stitched frame at
`A1_IMGSZ_STITCHED = 896`, and the cameras hold the arena photometry lock — exposure 200 / gain 64 /
white balance 4600 K, measured on site on 2026-07-20 and frozen in
`perception/calibration/photometry/arena.json`. The face weight in use was fine-tuned on
photographs of the real arena objects taken on 2026-07-24.

---

## 4. Outputs

<p align="center">
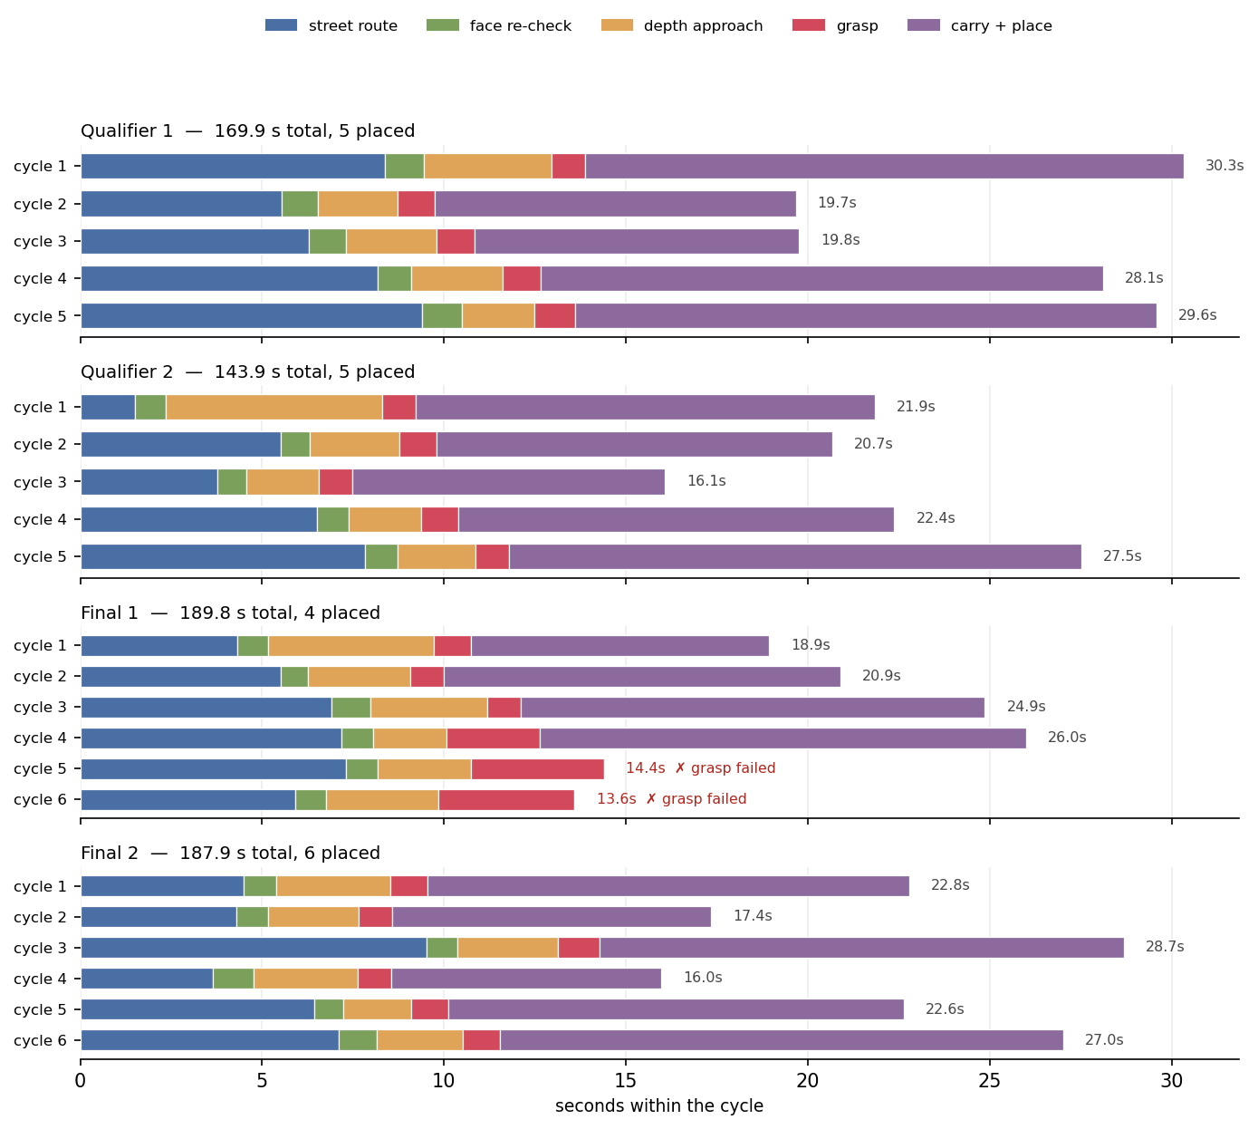
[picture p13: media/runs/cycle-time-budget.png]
Stacked bars showing how each collection cycle of the four matches divided its seconds between routing, face re-check, approach, grasp and carry
  
</p>
<p align="center"><em>Where the seconds went, from the four <code>report.json</code> files. A cycle is
routing plus a face re-check plus a depth-measured approach plus the grasp plus the carry back to
storage — the carry is the single largest slice, which is why the mini-goal is picked to shorten it.
Final 1's cycles 5 and 6 are the two grasps that came back empty.</em></p>

Everything lands in `logs/field_ops/<YYYYmmdd_HHMMSS>_e2e/`:

| File | Contents |
|---|---|
| `report.json` | The whole run. Rewritten after every stage and every cycle, so a run that dies mid-match still leaves a complete record up to that point. |
| `grid_map.json` | The confirmed 42-cell map: `cells[] = {cell, identity, votes, fruit_hits, conflict}` plus `presence[]`. Feed it back with `--skip-scan --map-file`. |
| `grid_map.png` | 440 × 440 px top-down render of the arena. Green dot = fruit cell, blue = polyhedron/plain, magenta = held on `conflicting_fruit`, orange ring = presence-only, plus the START and STORAGE zones. |
| `gt.json` | The layout the operator entered, if any. |
| `scan/shotNN_{top,near,stitched,overlay}.jpg` | Per shot: both raw camera frames (never only the stitched image), the stitched frame, and a debug overlay with boxes, class, confidence, range, snapped cell, and a red dot on the contact pixel. |
| `scan/shotNN_{top,near}_depth.png` | uint16 depth in mm (skipped on Pillow versions without uint16 support). |
| `stack_launch.log` | Only with `--launch-stack`. |

`report.json` keys that matter:

* `stages[]` — `{stage, ok, sec, detail}` for SEED / MAST_* / GOTO_CENTER / SCAN / COLLECT.
* `scan.shots[]` — per shot: yaw, detection count, votes cast, and every detection with
  `snap_err_m`, `status` (`vote` / `reject`) and `why` it was rejected.
* `scan.batch_timing` — seconds in stitch / A1 / geometry / face+pair.
* `scan.gt_compare` — ok / wrong / ghosts / missed against the entered layout. **Printed before
  collection starts**, so a bad scan is visible before the robot commits to picking anything.
* `cycles[]` — per collection: target cell, identity, `route`/`carry_route` waypoints and the reason
  the router chose them, `measure` (including `attempt`, `hop_attempt`, `src` = `depth`/`ground`,
  and `y_ground_ref` so the ground-vs-depth bias keeps being measured), `target_verify`,
  `place_gate`, `place_stall`, phase timings, `grasped`, `placed`, `fail`.
* `move_stats[]` — every relative move with elapsed vs expected seconds.
* `summary` — `score_est` (20 pts/fruit + 10 pts/shape actually placed), `placed_by_cls` vs quota,
  `total_sec` against the hard `match_budget_sec: 180`, effective parameters, and a
  `PASS` / `PARTIAL` / `FAIL` verdict.

---

## 5. Exit codes

| Code | Meaning |
|---|---|
| 0 | Ran to completion (a `PARTIAL` verdict still exits 0 — read the report). |
| 1 | Bad input the parser could not catch, e.g. `--map-file` points at a missing file; also `--offline` self-test failure. |
| 2 | Required topics missing at the health check. Also what argparse uses for a bad flag. |
| 3 | Operator aborted the physical checklist. |
| 4 | Localisation never locked after seeding. Driving without it is not safe. |
| 5 | Mast movement could not be confirmed. Stitching and back-projection calibration are height-dependent, so continuing would silently corrupt every measurement. |
| 6 | YOLO weights failed to load. |

The health check requires `/laser_scan`, arena status, `/motor/state`, both cameras' RGB **and**
depth, and `/chassis/odom`; IMU and gripper telemetry are optional topics, but the OpenRB board is
separately probed for real liveness — a board unplugged from USB keeps publishing
`{"width_mm": null, "error": true}`, and a topic-existence check happily passes that. That gap once
surfaced only at the first grasp attempt, minutes into a run: unrecoverable inside a 3-minute match.

---

## 6. The `--offline` self-test

A 2,500-line hardware script cannot be unit-tested conventionally, so the pure functions test
themselves with no ROS and no ultralytics installed:

* the GT text parser and the GT-vs-scan comparison,
* the corridor router on three hand-built cases, plus a **regression case** on a full 28-object
  arena asserting the returned path actually clears every obstacle (on 2026-07-20 the detour branch
  computed a waypoint and never checked it, driving a carry route through 6 obstacle cells with 4.8 cm
  minimum clearance),
* the 42-cell snap,
* the storage pin layout (prints each pin's robot target and predicted object position, and which
  pins are rejected for putting the object outside the box),
* the competition candidate filter: non-target and conflicted cells excluded, an exhausted quota
  removing a class, `fruit-first` reordering.

Run it after any edit to the routing or target logic. It exits 1 if anything fails.

---

## 7. Where the reasoning lives

`mission/docs/match-strategy.md` — why the scan happens where it does, why measurements come from
depth instead of the ground plane, why a "plain" reading right before a grasp is not a reason to
skip, the storage geometry, and what we would change after losing points three different ways.

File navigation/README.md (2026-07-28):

# Navigation — we deleted Nav2

This directory holds the localisation and control stack, plus `street_nav.py` — the north-locked closed loop that actually drove every match. It is the **entire** navigation system of the robot that won the SNU AI ROBOT CHALLENGE 2026 (1st of 16 teams). There is no Nav2, no AMCL, no EKF, no costmap, no global/local
planner pair, no behaviour tree, no TF tree, and no RViz.

What is here instead is one `rclpy` node. It reads a known 4 m × 4 m occupancy map, one RPLIDAR
A2M12 scan and one D435I gyro, and publishes `geometry_msgs/Twist` on `/cmd_vel_direct` at 20 Hz.
The localisation and control maths is pure Python standard library — `math`, `heapq`, `dataclasses`.
No numpy in the hot path.

| | lines | what it is |
|---|---:|---|
| `ALC/arena_control_node.py` | 1384 | the runtime node: scan → pose, goal → Twist, status JSON |
| `ALC/map_localization.py` | 1004 | PGM/YAML map loader, wall-range matcher, distance-field matcher |
| `ALC/controllers.py` | 218 | `DiffDriveController`, `MecanumController`, one shared config dataclass |
| `ALC/web_ui.py` | 514 | the whole operator console, `http.server` + one embedded HTML string |
| `ALC/tk_ui.py` | 745 | optional Tk desktop UI (disabled on match day) |
| `launch/lightweight_real.launch.py` | 370 | the single launch file |

> Throughout this directory, `ALC/` abbreviates
> `navigation/ros2/arena_lightweight_control/arena_lightweight_control/`.

---

<p align="center">
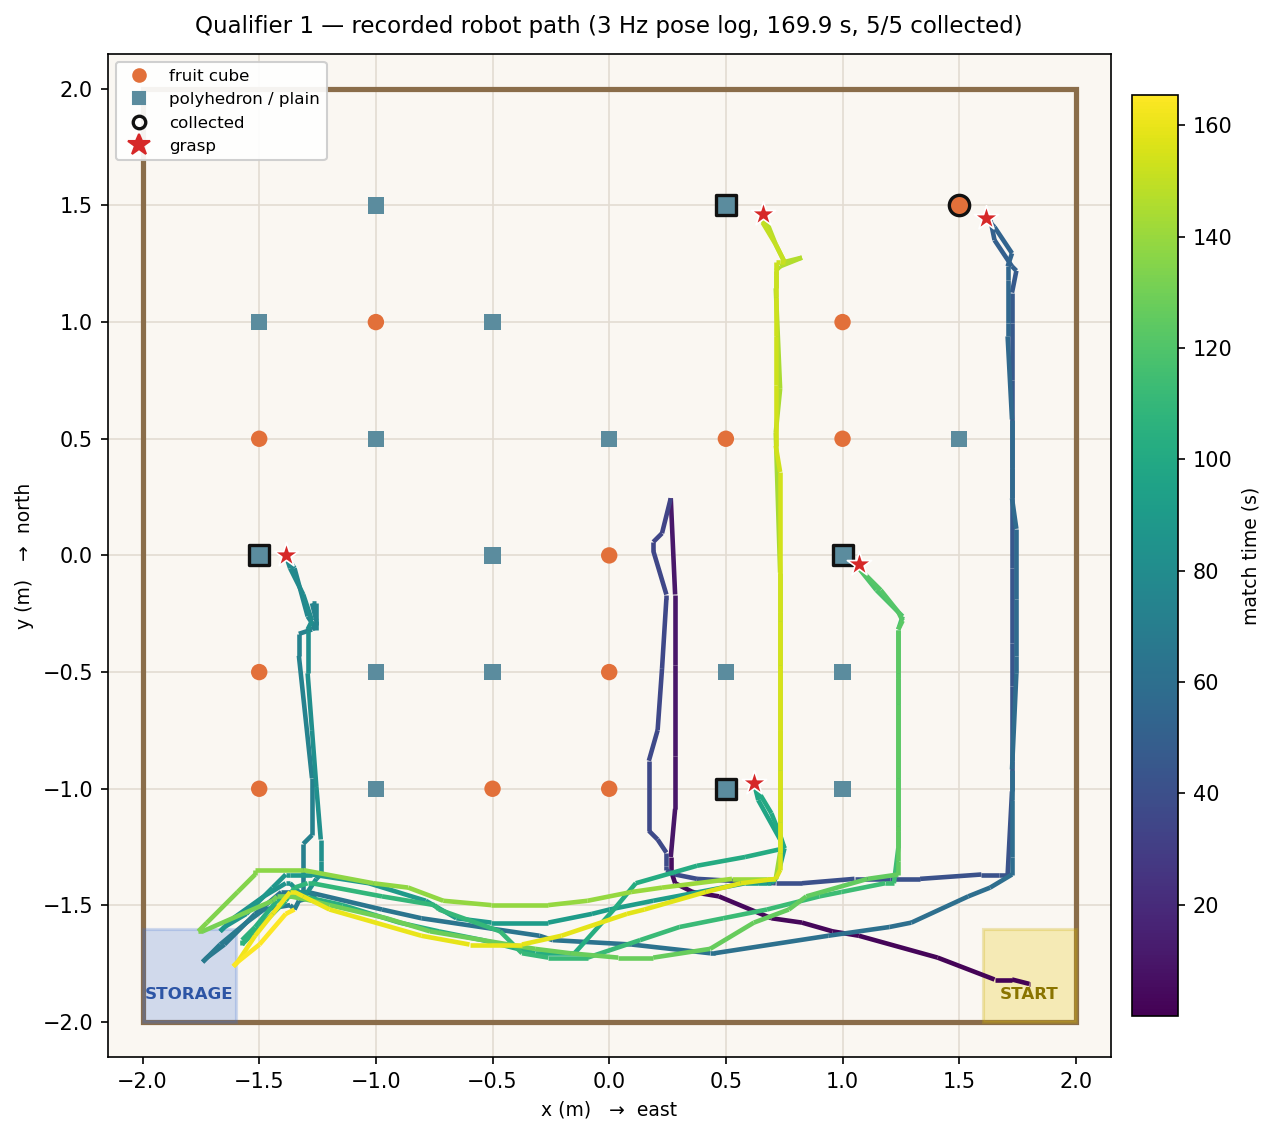
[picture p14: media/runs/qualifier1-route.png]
Path the robot drove during Qualifier 1, plotted over the 42-point grid: a highway along the south edge with straight northward legs to each target
  
</p>
<p align="center"><em>Every metre the robot drove in Qualifier 1, from its own 3 Hz pose log
(the one match recorded with <code>--frame-rec-fps 3</code>). The shape is the whole strategy:
one highway along the south edge, straight northward legs up a street to each target, and back.
Heading is locked north on every leg — the gripper sticks out 26 cm past the lidar centre, so
turning into a 21 cm corridor is what a sideways sweep costs.</em></p>

<p align="center">
  The arena control web UI: the arena map with the 42-point grid, the storage and start zones, the robot pose and the clicked goal, beside a panel of buttons and live metrics
</p>
<p align="center"><em>What replaced RViz. <code>arena_control_node</code> serves this page itself on
port 18765 — click anywhere on the arena to set a goal, and the same panel drives the gripper and
the mast. No Nav2, no TF tree, no RViz on the robot. Shown here filled with a pose and a
localisation result recorded during Qualifier 1.</em></p>

<!-- Isaac Sim screenshot of the arena with the robot mid-route
     -> media/simulation/isaac-arena.jpg, then uncomment. -->

## Why we deleted it

We started on the standard stack: Isaac Sim + Nav2 + AMCL + EKF, `map → odom → base_link`, RViz
goals. It ran. It was also, for this specific problem, the wrong tool, and we have the measurement
that convinced us.

On **2026-07-04**, full known-map scan matching — a generic occupancy-grid correlative matcher over
a distance field, i.e. the honest general-purpose approach — was measured at **345–449 ms per scan**
in a real robot run (the 22:54 log). To be explicit, that is the latency of the approach we
*abandoned*, not of anything in this directory.

At that latency the pose estimate is more than three LiDAR periods stale. This was not a
theoretical concern: in the same log the node injected `wz = 0.416, -0.538, 0.521` while the robot
was supposed to be driving straight. Yaw jumped, the controller chased the jumps, and the straight
lines bent.

The arena, however, is a **known empty rectangle**. Nothing in the arena is taller than 8 cm; the
LiDAR plane sits at 0.32 m. Every single return is a wall. That is an enormously strong prior, and
the general matcher throws all of it away.

Rewriting the matcher to score each beam against the *analytically expected wall range* of a
rectangle brought the same job to **~20.35 ms** on a synthetic 1080-beam scan — a 17–22× reduction —
and made the whole Nav2 layer above it unnecessary. The rewrite is ~90 lines
(`ALC/map_localization.py:706-771`).

### Before → after

| Nav2 component | what we run instead |
|---|---|
| `nav2_amcl` particle filter | closed-form wall-range grid search, ~200 candidates/scan (`WallRangeLocalizer`) |
| `robot_localization` EKF | gyro-z integration fed **forward** into the pose yaw between scans |
| global + local costmap | a static 25 cm "street" grid derived from the rulebook object layout |
| NavFn / Smac planner | `plan_route()` — direct → axis-aligned L → street grid → verified detour |
| DWB / MPPI controller | `MecanumController`: proportional holonomic command, 20 Hz, ~40 lines |
| behaviour tree + recovery | an explicit Python state machine in `mission/match_runner.py` |
| TF tree (`map→odom→base_link`) | one `Pose2D` in map frame, guarded by a revision counter |
| RViz | a dependency-free web page on port 18765 |

---

## Measured results

> The first row is the approach this stack **replaced**, not this stack. Everything
> below it is `wall_range`, what actually shipped.

| quantity | value | where measured |
|---|---|---|
| ✗ *replaced:* generic occupancy-grid matcher (the Nav2/AMCL approach) | 345–449 ms | real-robot run log, 2026-07-04 22:54 — the reason for the rewrite |
| ✓ wall-range matcher latency | ~20.35 ms | synthetic 1080-beam scan, 2026-07-04 (32 beams, ~272 coarse+refine candidates) |
| ✓ wall-range matcher, yaw-locked global solve | 8–10 ms | offline, 2026-07-07 |
| ✓ on-robot localisation latency (Jetson Orin Nano) | median **28.2 ms**, mean 38.9 ms, p95 185 ms, max 300 ms (n = 2132 scans) | `loc_latency_ms` in three real-arena capture sessions, 2026-07-18 |
| watchdog budget | 50 ms (`localization_warn_latency_ms`) | `ALC/arena_control_node.py:113` |
| positional accuracy vs. ground truth | 2.7–2.9 cm | Isaac kinematic parity study, 2026-07-18 |
| positional accuracy, synthetic reference scan | 2 cm | 2026-07-07 after the short-return fix |
| pose jitter while rotating in place | 1.5–2 cm | real arena, 2026-07-18 |
| route safety after the router fix | 0/28 targets intruded, min. object clearance **0.250 m** | offline replay over the real 28-cell ground-truth layout, 2026-07-20 |
| route safety before the fix | 6 cells traversed inside the inflation radius, min. clearance **4.8 cm** | real run 06:23, 2026-07-20 |
| drive speed, `fast` profile | 5.65–6.13 s over the centre-approach leg (0.51–0.56 m/s) | 25 timed runs, 2026-07-20 |
| chassis physical limit | 1.22 m/s | 2026-07-17 |

The p95 of 185 ms is not a typo and we are not hiding it: those captures ran the two-stage YOLO
pipeline on the same Jetson, and Python's GIL is shared. The mitigations — `depth=1` scan QoS so
stale scans are dropped rather than queued, and a 12.5 Hz software throttle on scan processing —
are described in [`docs/localization.md`](docs/localization.md#latency).

---

## Runtime shape

```mermaid
flowchart LR
  LIDAR[RPLIDAR A2M12<br/>/laser_scan] --> NODE
  IMU[D435I gyro<br/>/imu/data] --> NODE
  MAP[(stadium.yaml<br/>4x4 m walls)] --> NODE
  NODE[arena_control_node<br/>10 Hz match / 20 Hz control]
  MISSION[mission/match_runner.py<br/>street router + state machine] -->|JSON goal| NODE
  WEB[web UI :18765] -->|POST /goal| NODE
  NODE -->|/cmd_vel_direct| MUX[cmd_vel_mux]
  NODE -->|/arena_lightweight/status 20 Hz| MISSION
  MUX --> MOTOR[mecanum_bridge_node -> Arduino UNO]
```

### Topic contract

| topic | type | direction | note |
|---|---|---|---|
| `/laser_scan` | `sensor_msgs/LaserScan` | in | QoS `depth=1`, sensor-data reliability |
| `/imu/data` | `sensor_msgs/Imu` | in | BEST_EFFORT subscription (RealSense publishes BEST_EFFORT) |
| `/chassis/odom` | `nav_msgs/Odometry` | in | fallback yaw prior only |
| `/arena_lightweight/goal` | `std_msgs/String` (JSON) | in | `{"x":…, "y":…, "yaw":…}` — `yaw` optional |
| `/arena_lightweight/pose` | `std_msgs/String` (JSON) | in | pose seed; **mandatory before every run** |
| `/arena_lightweight/control` | `std_msgs/String` | in | `STOP` / `CLEAR` / `CLEAR_GOAL` |
| `/cmd_vel_direct` | `geometry_msgs/Twist` | out | 20 Hz, highest-priority mux input |
| `/arena_lightweight/status` | `std_msgs/String` (JSON) | out | 20 Hz in the competition launch (the node default is 4 Hz; the street loop needs 20); pose, match score, latency, phase, stamp |
| `/gripper/command` | `std_msgs/String` | out | relayed from the UI only |

---

## The three ideas that make it work

**1. Exploit the rectangle.** For a candidate pose `(x, y, yaw)` the expected range of a beam is a
closed-form ray/rectangle intersection — four divides and a `min`
(`ALC/map_localization.py:744-771`). Scoring a candidate is ~30 float operations per beam, against
16–24 downsampled beams. No ray casting, no map lookups, no distance field.

**2. Make yaw known, then the square stops being ambiguous.** A square arena's wall-range
observation is 90°-degenerate: four poses fit the same scan equally well, and a matcher can silently
jump a quadrant. We integrate gyro-z into `pose.yaw` *continuously between scans*, so yaw is never
being estimated from the scan at all. With yaw fixed, the x/y solution is unique, so the matcher
solves **globally** every scan on a single-yaw grid (~200 candidates) instead of tracking a fragile
local window. See [`docs/localization.md`](docs/localization.md).

**3. Plan on streets, not on a costmap.** The rulebook puts objects only on a 50 cm grid. The lines
halfway between grid columns are 25 cm corridors that are free *by construction*. The router
therefore never inflates and searches — it snaps onto that fixed grid and verifies. See
[`docs/control-and-routing.md`](docs/control-and-routing.md).

---

## What you give up

Publishing this as "delete your framework" advice would be dishonest. The stack is fast because it
assumes things that are true in this competition and false almost everywhere else:

- **The map must be known, rectangular, and correct.** `WallRangeLocalizer` derives the inner wall
  rectangle from the PGM (`ALC/map_localization.py:123-159`). A non-rectangular room breaks the
  observation model outright.
- **The LiDAR plane must clear every obstacle.** Scoring assumes no occlusion (0.32 m plane vs. 8 cm
  objects). Put a person in the arena and short returns become real occlusions, not noise.
- **The initial pose must be seeded by an operator.** The square's 4-fold symmetry is resolved by
  the seed plus the gyro; there is no global relocalisation from scratch. A wrong seed produces a
  confident, wrong pose in a mirrored corner — which is exactly what happened to us twice in
  rehearsal.
- **No dynamic obstacle avoidance worth the name.** There is a front-sector emergency stop and an
  optional semantic keep-out (off by default). Everything else is planned open-loop against a static
  object list.
- **No TF.** Anything downstream that wants `map → base_link` has to be written against the JSON
  status topic instead. That is a real integration cost we paid inside `perception/fieldlib.py`.

If your arena is known, static, small, and rectangular, this is a good trade. Otherwise, use Nav2.

---

## Contents

```
navigation/
├── README.md                       this file
├── docs/
│   ├── localization.md             the wall-range matcher, the IMU yaw prior, the symmetry problem
│   └── control-and-routing.md      goal latch, mecanum controller, speed profiles, the street router
└── ros2/arena_lightweight_control/
    ├── arena_lightweight_control/  the node + matchers + controllers + web UI
    ├── launch/lightweight_real.launch.py
    └── maps/stadium.yaml, stadium_nav2_map.pgm
            5x5 m canvas at 0.02 m/px (250x250), origin [-2.5,-2.5,0], walls at +/-2 m.
            The canvas is deliberately larger than the arena so a scan origin next to a
            wall still falls inside the grid.
```

The street router itself lives with the mission layer, in `mission/match_runner.py:284-431` — it is a
set of pure functions with no ROS dependency, unit-testable offline, and it is documented in
[`docs/control-and-routing.md`](docs/control-and-routing.md#the-street-router).

## Running it

```bash
source /opt/ros/humble/setup.bash
source install/setup.bash

# full stack (hardware bridge + arena node); mecanum is the competition configuration
DRIVE_TYPE=mecanum IMU_TOPIC=/imu/data BASE_SCAN_YAW=0.0 \
  ENABLE_WEB_UI=true LAUNCH_PYTHON_UI=false \
  bash scripts/run_lightweight_arena_control.sh

# arena node only, on top of an already-running bridge (the match-day form —
# never start two motor bridges on one Arduino serial port)
ros2 launch arena_lightweight_control lightweight_real.launch.py \
  launch_bridge:=false controller_type:=mecanum \
  base_scan_yaw:=0.0 initial_pose_yaw:=1.5708

# seed the pose - mandatory, the square arena cannot resolve its own corner
ros2 topic pub --once /arena_lightweight/pose std_msgs/String \
  '{data: "{\"x\":1.8,\"y\":-1.8,\"yaw\":1.5708}"}'
```

Operator console: `http://<jetson>:18765` (click to set a goal, shift-click to seed a pose). If the
port is taken the server walks forward up to 25 ports and logs the URL it actually bound.

## Tests

```bash
python3 -m pytest tests/test_map_localization.py tests/test_controllers.py tests/test_web_ui.py
```

34 test functions covering both matchers, the global reseed escaping a bad prior, short-return handling,
both controllers, the goal latch hysteresis, and the web server's port fallback. They need only
`pytest` — no ROS, no numpy.

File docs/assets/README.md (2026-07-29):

# Figures

| File | What it shows | Source |
|---|---|---|
| `synthetic-training-samples.jpg` | Six BlenderProc scenes with renderer-emitted YOLO-seg ground truth, including one hard negative | `meta_v2_topfruit_*` render sets |
| `real-face-crops.jpg` | Ten real arena cube crops with ground truth and detection range | `face_model_compare` crop set, real captures of 2026-07-18 |
| `final-standings-{light,dark}.svg` | The official final standings, each bar split into its two match scores | Organisers' scoreboard, 2026-07-24 |
| `arena-grid-official.png` | The arena as specified: 7 × 6 candidate points at 50 cm pitch, the 100 cm empty bottom band, storage and starting points | The organisers' own figure, supplied to the teams |

The standings chart is regenerated by `make_leaderboard.py` (no inputs — the
scores are in the script). The two photographic sheets were built from the
render sets and a real arena capture, neither of which ships here.

## The standings chart

Two SVGs, one per GitHub theme, selected with `<picture>` in the README rather
than flipped automatically — the dark variant uses its own steps from the same
palette, not inverted colours.

Series colours are categorical slots 1 and 2 of the reference data-viz palette,
checked with its validator against both surfaces: worst adjacent CVD ΔE 24.7
light / 26.8 dark, well above the 8 target. Rank is never encoded in colour —
hue means *which match*, and the winner is marked with a background band and
weight instead, so a filter or a re-sort could never repaint the series.

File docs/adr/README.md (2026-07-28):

# Architecture Decision Records

Five decisions shaped this robot more than any other. Each record states the situation that
forced the choice, what was chosen, and what it cost — the costs are the part worth reading.
All of them are grounded in measurements or failures from this project, not in general
principle.

| # | Decision | Status | One-line summary |
|---|---|---|---|
| [0001](0001-drop-nav2.md) | Drop Nav2 | Accepted 2026-07-04 | Full scan matching cost 345–449 ms in an empty known square; a hand-written wall-range matcher does it in 8–10 ms offline / ~41 ms on the Jetson — at the price of no planner, no obstacle avoidance and no reusable stack. |
| [0002](0002-json-over-std-msgs-instead-of-custom-messages.md) | JSON over `std_msgs/String` instead of custom messages | Accepted, with a known failure | Every payload is echo-able and pub-able from a field terminal; the interface package stayed empty. A misread key (`grasp_state` vs `state`) then made every successful grasp score as a failure. |
| [0003](0003-firmware-owns-motion-primitives.md) | Firmware owns the motion primitives | Accepted 2026-07-14 | The Arduino runs the velocity PID and a synchronised 4-wheel trapezoidal position profile, so moves are immune to host load — but deadlines, state and buffer limits now live across a serial link. |
| [0004](0004-simulation-is-kinematic-only.md) | The simulation is kinematic only | Accepted 2026-07-07 | Isaac Sim is a surrogate for perception and mission logic; physics was validated on the real robot. Grasping in sim is faked and sim timing runs 2.4–2.9× slow. |
| [0005](0005-synthetic-only-training-data.md) | Synthetic-only training data | Accepted, later amended | Zero hand-labelled images; everything rendered in Blender. It survived a rule change four days before the competition, and it lost the qualifiers to an under-ripe apple. |

## Format

Each record is Context / Decision / Consequences / Status. Consequences always list costs,
including the ones we paid publicly. If a decision was later amended, the amendment is in
the Status line rather than in a new record — this is a frozen project, not a living
codebase.

## Related reading

- [`docs/02-architecture.md`](../02-architecture.md) — how the three parts compose.
- [`docs/07-results-and-lessons.md`](../07-results-and-lessons.md) — measured outcomes and
  the three competition failures.
- [`simulation/docs/field-parity.md`](../../simulation/docs/field-parity.md) — the evidence
  behind ADR-0004.

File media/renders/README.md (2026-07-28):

# 3D renders

Rendered stills of the robot, supplied by the team. **24 frames**: a turntable at
60° steps in four configurations. Delivered as PNG, stored here as WebP — 9.3 MB
of near-identical grey-background renders compresses to 0.9 MB with no visible
loss, and this repository deliberately has no LFS.

| Mast | View | Files |
|---|---|---|
| up | iso | `mast-up_iso_00.webp` … `_05.webp` |
| up | side | `mast-up_side_00.webp` … `_05.webp` |
| down | iso | `mast-down_iso_00.webp` … `_05.webp` |
| down | side | `mast-down_side_00.webp` … `_05.webp` |

`00` is the front of the robot (gripper toward the camera) and the index
increases with the turntable, 60° per step. If the files arrive named
differently, rename them to this scheme rather than editing the consumers —
everything below is generated from these names.

## What gets built from them

| Output | Made from | Used by |
|---|---|---|
| `robot-hero.webp` | one iso frame, mast up | root `README.md` header |
| `robot-overview.webp` | one iso frame, mast down | `hardware/README.md`, root `README.md` |
| `mast-up-down.webp` | the two side frames at the same angle, side by side | `hardware/README.md` |
| `robot-turntable.webp` | the six iso frames, looping | root `README.md` |

The mast comparison is the one that earns its place: two mast heights means two
camera calibrations, and the perception documents refer to that difference
constantly.

## No interactive viewer

There is no `.glb` export and no GitHub Pages model viewer. GitHub strips scripts
and canvases from rendered Markdown, so a live 3D viewer could never have run
inside a README; the looping turntable is what a reader actually sees.

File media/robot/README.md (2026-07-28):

# Robot photographs

| File | What it is | Used by |
|---|---|---|
| `competition-run.jpg` | The robot mid-match in the arena, objects laid out on the 42-point grid | `README.md` hero |
| `robot-closeup.jpg` | The built robot held up after the final, cropped from `../award/award-with-robot.jpg` — the clearest look at the gripper, mast, lidar and wiring | `hardware/README.md` |

Still worth adding, if you have them:

- `gripper-closeup.jpg` — the parallel gripper holding an object.
- `mast-closeup.jpg` — the camera mast with both RealSense units.
- `electronics.jpg` — the wiring, for `hardware/docs/wiring-and-firmware.md`.

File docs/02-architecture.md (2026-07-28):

# 02 — System Architecture

How the robot is put together: what runs where, what talks to what, and why the boundaries
are drawn where they are.

The one-line version: **motion primitives live in firmware, device ownership lives in ROS 2
bridges, world state lives in a single localisation/control node, and the match itself is one
plain Python process that drives all of it over topics.** There is no Nav2, no AMCL, no
`robot_state_publisher`, no behaviour tree, and no custom ROS message package.

---

## 1. Physical compute topology

Three processors, connected by two USB serial links and one Dynamixel bus.

| Where | Hardware | What runs there | Link to the rest |
|---|---|---|---|
| **Onboard computer** | Jetson Orin Nano (8 GB) | All ROS 2 Humble nodes, both YOLO models, stitching, the match runner | USB3 to 2x RealSense, USB to LiDAR, USB-serial to Arduino and OpenRB |
| **Drive controller** | Arduino UNO | 4x quadrature encoder decode, per-wheel velocity PID, synchronised trapezoidal position profiles, 2x Cytron MDD10A output | ASCII lines @ 115200 8N1 |
| **Manipulator controller** | ROBOTIS OpenRB-150 | Gripper XC330 (current-based position mode) and camera-mast lift XC330 (ID 12, multi-turn), mast homing, torque-fault latch | ASCII lines @ 115200; Dynamixel bus @ 1 Mbps |

Sensors: 2x Intel RealSense D435/D435i on the servo-driven camera mast (top + near),
RPLIDAR A2M12 2D scanner, and the bottom D435i's IMU (used as a yaw prior, not for full
fusion). Everything is on the robot; there is no off-board compute and no network dependency
during a match.

---

## 2. The four layers

```mermaid
flowchart TB
    subgraph L4["Layer 4 — Mission (one plain rclpy process)"]
        MR["match_runner.py<br/>state machine + 2-stage YOLO + stitching<br/>+ depth back-projection, all in-process"]
    end

    subgraph L3["Layer 3 — Arena control (Nav2-free, one ROS node)"]
        AC["arena_control_node<br/>known-map scan matching + IMU yaw prior<br/>goal latch -> mecanum velocity controller"]
        WEB["web_ui (:18765)<br/>click-to-goal, operator only"]
    end

    subgraph L2["Layer 2 — ROS 2 device bridges (one process per device)"]
        RS["realsense2_camera_node x2"]
        LID["sllidar_node"]
        WD["laser_scan_watchdog_node"]
        MUX["cmd_vel_mux_node"]
        MEC["mecanum_bridge_node"]
        GRIP["gripper_bridge_node"]
    end

    subgraph L1["Layer 1 — Firmware (owns motion primitives)"]
        ARD["Arduino UNO<br/>velocity PID + trapezoidal position moves"]
        ORB["OpenRB-150<br/>gripper + mast servo control, homing, fault latch"]
    end

    HW["Motors / wheels / gripper / mast / cameras / LiDAR"]

    MR -->|"JSON goals, relative moves,<br/>gripper + lift commands"| L3
    MR -->|"raw images + depth,<br/>move_relative, gripper/lift"| L2
    AC -->|"/cmd_vel_direct"| MUX
    WEB --- AC
    L2 -->|"/arena_lightweight/status,<br/>images, scans, odom, grasp state"| MR
    WD --> AC
    MUX --> MEC
    MEC <-->|"ASCII serial 115200"| ARD
    GRIP <-->|"ASCII serial 115200"| ORB
    RS --- HW
    LID --> WD
    ARD --> HW
    ORB --> HW

    classDef l1 fill:#fde,stroke:#a66
    classDef l4 fill:#def,stroke:#69a
    class ARD,ORB l1
    class MR l4
```

The detailed topic-by-topic graph (every publisher, subscriber, QoS profile and serial
line) is in [03-ros2-interfaces.md](03-ros2-interfaces.md). This document only explains the
shape.

---

## 3. Layer 1 — firmware owns the motion primitives

The Arduino sketch (`hardware/firmware/arduino_mecanum/mecanum_encoder_control.ino`) is not
a dumb PWM relay. It exposes two independent control modes over one serial line:

| Command | Mode | Firmware does |
|---|---|---|
| `m <vx> <vy> <wz>` | velocity | mecanum inverse kinematics, then per-wheel velocity PID with feedforward |
| `d <dx> <dy> <dyaw>` | position | synchronised trapezoidal profile on all four wheels; replies `OK move`, then `DONE,move,...` or `ERR move timeout` |
| `pid` / `ppid` / `geom` / `sign` / `mstyle` | config | gains, geometry, wiring polarity and driver-board PWM encoding, all settable at runtime |

Everything is pushed from the ROS bridge at startup (`push_firmware_config`), so the
measured robot geometry lives in one YAML file
(`hardware/ros2/robot_bringup/config/real.yaml`: `wheel_radius 0.0388`, `half_length 0.108`,
`half_width 0.090`, `encoder_cpr 1320`, per-wheel motor and encoder signs) and is *pushed
down* rather than compiled in. Changing wiring polarity or swapping a motor driver never
requires reflashing.

Why put the loops in firmware:

* **Jitter.** A 10 Hz Python control loop on a Jetson that is simultaneously running two
  RealSense pipelines and two YOLO models cannot close a wheel velocity loop. The Uno can.
* **Deterministic short moves.** The last 10 cm before a grasp are the moves that matter.
  `d dx dy dyaw` gives a repeatable displacement with a completion signal, which is a much
  stronger primitive than "publish a Twist and hope". The match runner uses closed-loop
  arena goals for long hauls and `d` moves for centimetre-scale approach and storage
  placement.
* **Safety.** The firmware stops on its own if commands stop arriving; the ROS bridge has a
  0.5 s `command_timeout_sec` on top of that
  (`hardware/ros2/robot_bringup/config/real.yaml:74`).

The same philosophy applies to the OpenRB-150. It owns the gripper's current-based position
mode, the current-fault latch, a 3 s watchdog, and — critically — the **mast home capture**:
the lift's zero is the servo position observed the first time the lift is initialised after
power-on, and the top of travel is `LIFT_STROKE_TICKS = 31641` from there (measured: bottom
`POS_RAW 33122`, top `1481`). That home only exists in the board's RAM.

> **One TTY, one owner.** Opening the OpenRB serial port toggles DTR and reboots the board,
> which destroys the captured lift home; a subsequent `LIFT_TO_TOP` then drives the mast into
> its hard stop. `gripper_bridge_node` is therefore the *only* process allowed to touch that
> port, and it carries an explicit `LIFT_*` pass-through on `/gripper/command` in addition to
> `/lift/command` so that no tool ever needs to open the tty directly. This is enforced in
> code and repeated in the field runbook.

---

## 4. Layer 2 — one bridge process per device

Each ROS node in this layer owns exactly one piece of hardware and translates between its
native protocol and topics. The competition bringup
(`hardware/ros2/robot_bringup/launch/real_competition_bridge.launch.py`) starts these and
nothing else:

| Process | Owns | Emits |
|---|---|---|
| `realsense2_camera_node` x2 | top D435 (`/camera_19/*`), near D435i (`/camera_54/*`) | RGB 1920x1080x15 + aligned depth 848x480x15, `camera_info`, `/imu/data` |
| `sllidar_node` (vendored) | RPLIDAR A2M12 @ 256000 baud | `LaserScan` on `/scan_raw` |
| `laser_scan_watchdog_node` | nothing — it is a rate/robustness shim | `/laser_scan` (+ `/scan` alias) at a steady 15 Hz |
| `static_transform_publisher` | — | static `base_link -> base_scan` |
| `cmd_vel_mux_node` | — | `/cmd_vel_motor` at 30 Hz |
| `mecanum_bridge_node` | Arduino UNO tty | `/chassis/odom`, `/joint_states`, `/motor/state`, `/base/move_result`, dynamic TF `odom -> base_link` |
| `gripper_bridge_node` | OpenRB-150 tty | `/gripper/state`, `/gripper/grasp`, `/lift/state` |
| `gripper_joint_command_bridge` | — | Isaac-parity shim: `JointState` aperture -> `OPEN`/`CLOSE` |

Two of these are worth calling out because they are fixes, not boilerplate:

**`laser_scan_watchdog_node`.** The entire localisation loop is one Python node consuming one
topic. A single USB hiccup on the LiDAR would freeze the pose estimate mid-drive. The
watchdog decouples driver jitter from consumer rate: publish-on-receive *plus* a 15 Hz timer
that re-emits the last scan while it is younger than `hold_stale_scan_sec = 1.25`, falling
back to an all-`inf` empty scan after that
(`hardware/ros2/robot_bringup/robot_bringup/laser_scan_watchdog_node.py:21-55`).

**`cmd_vel_mux_node`.** Priority order is `/cmd_vel_direct` > `/cmd_vel` > `/cmd_vel_nav`,
each with a 0.4 s freshness timeout. When *every* source is stale it does not go silent — it
actively publishes a zero `Twist`, so the firmware's own timeout is a second line of defence
rather than the only one
(`hardware/ros2/robot_bringup/robot_bringup/cmd_vel_mux_node.py:29-32, 91`).

---

## 5. Layer 3 — arena control, and the two edges of the TF tree

`arena_control_node` (`navigation/ros2/arena_lightweight_control/arena_lightweight_control/arena_control_node.py`)
is the only node that knows where the robot is. It matches `/laser_scan` against a 0.02 m/px
occupancy grid of the 4 m x 4 m arena (`navigation/ros2/arena_lightweight_control/maps/stadium.yaml`),
gated by an IMU gyro-z yaw prior, latches a goal, and emits a `Twist` on `/cmd_vel_direct`
through a mecanum goal controller.

Deliberate omissions, each of which removes a failure mode:

* **No `map -> odom` TF and no AMCL.** The map-frame pose is kept internally and shipped as
  a JSON blob on `/arena_lightweight/status`. Nothing in the system needs to do a TF lookup
  to know where the robot is, so nothing can fail on a missing or late transform.
* **The TF tree is two edges**: dynamic `odom -> base_link` from `mecanum_bridge_node`, and
  static `base_link -> base_scan`. No URDF is loaded at match time. Camera and gripper
  geometry are measured numeric constants in `perception/fieldlib.py:35-56` (e.g.
  `NEAR_MOUNT_DOWN` forward 0.1874 m, height 0.3143 m, tilt 53.20°; mast stroke 14.89 cm)
  rather than TF frames — because the mast moves, and a frame that is only correct at two
  discrete heights is more dangerous than an explicit per-height calibration dictionary.
* **`depth=1` sensor QoS on the scan subscription.** When matching falls behind, stale scans
  must be *dropped*, not queued: a backlog of five 300 ms scans once made the pose estimate
  seconds-stale. The comment survives in the code at `arena_control_node.py:352-358`.

The embedded web UI (port 18765) is an operator tool — click-to-goal, live map, gripper
buttons. It was not used during matches (the competition bring-up leaves `ENABLE_WEB_UI` off and
overrides `LAUNCH_PYTHON_UI` to false), but it is how almost all
of the driving was debugged.

---

## 6. Layer 4 — the mission is a script, not a node

The competition brain is `mission/match_runner.py`: a 2,508-line plain `rclpy` process, not
a ROS package node. It subscribes to the camera, depth, `camera_info`, odom, scan, IMU,
status and gripper topics; it publishes goals, relative moves, gripper and lift commands.
It runs the image stitch, both YOLO stages, the pair verifiers and the depth back-projection
**in its own process**.

This is unusual enough to justify:

* **One process, one GPU context.** Two YOLO models plus two RealSense pipelines already
  strain an 8 GB unified-memory Orin Nano. Splitting perception into separate nodes would
  mean multiple CUDA contexts and copying full-resolution images across DDS. Inference batch
  sizes had to be chunked (A1 in chunks of 8, face in chunks of 32) because a single 65-crop
  batch exhausted memory outright — that kind of tuning is far easier inside one process.
* **Sequencing is inherently procedural.** "Raise mast, drive, spin 8 times, lower mast,
  then for each target: route, face, measure, verify, grasp, carry, place" is a script. A
  behaviour tree or a node-based state machine buys nothing here and costs a rebuild cycle
  on every edit — and edits were happening hourly in the last 48 hours before the
  competition.
* **It is testable without ROS.** `match_runner.py --offline` self-tests the argument
  parser, the ground-truth layout parser, the corridor/street router and the two-set
  candidate filter using nothing but numpy. A 2,500-line hardware script with no test story
  would be indefensible; this is the pragmatic answer.
* **The stack keeps running when the brain dies.** The runner can be killed and restarted
  mid-session without touching the hardware bridges, the mast home, or the localiser lock.

There *is* a ROS-node state machine in the project history (`robot_task_planner`), written in
June for a Nav2 + semantic-mapping design. It was never launched at the competition and is
not in this repository.

---
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

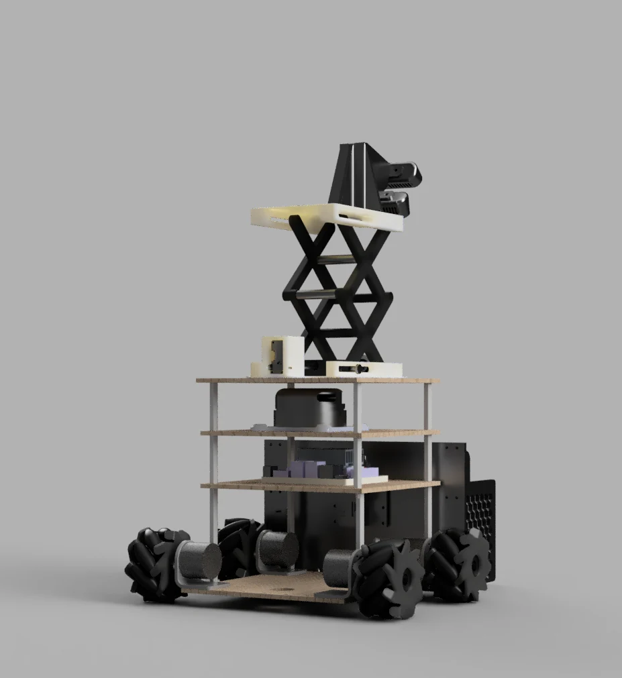
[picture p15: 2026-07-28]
media/renders/mast-up_side_04.webp

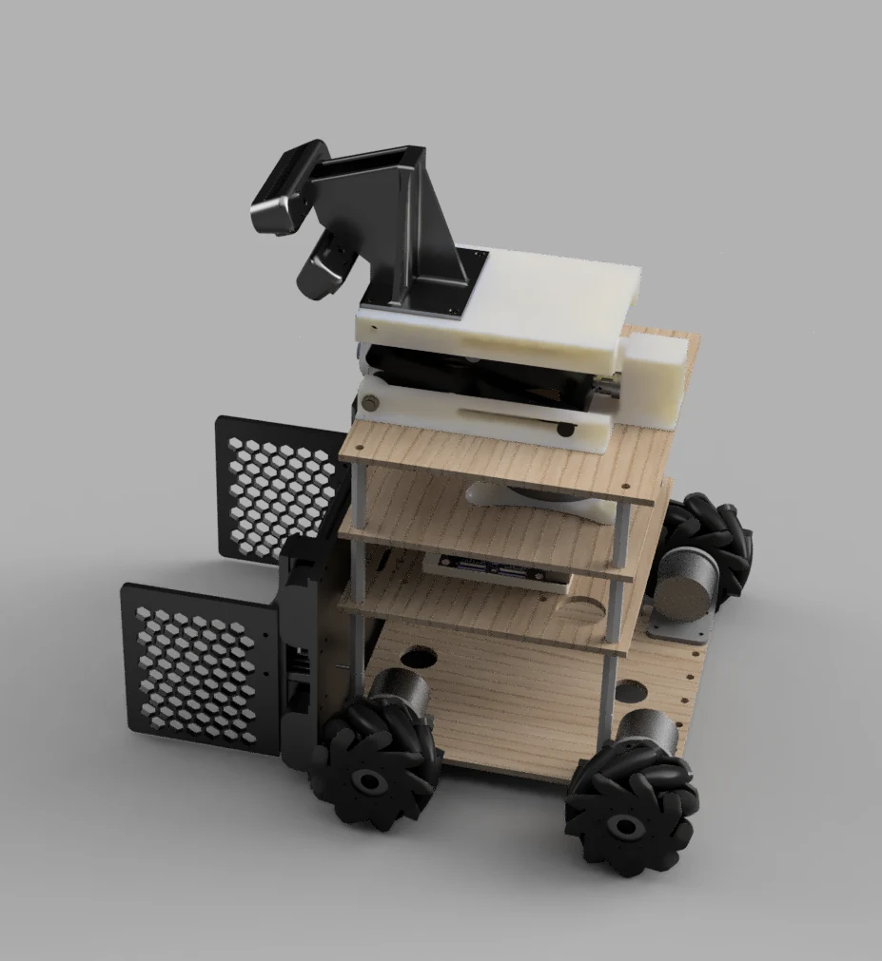
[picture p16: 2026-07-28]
media/renders/mast-down_iso_05.webp

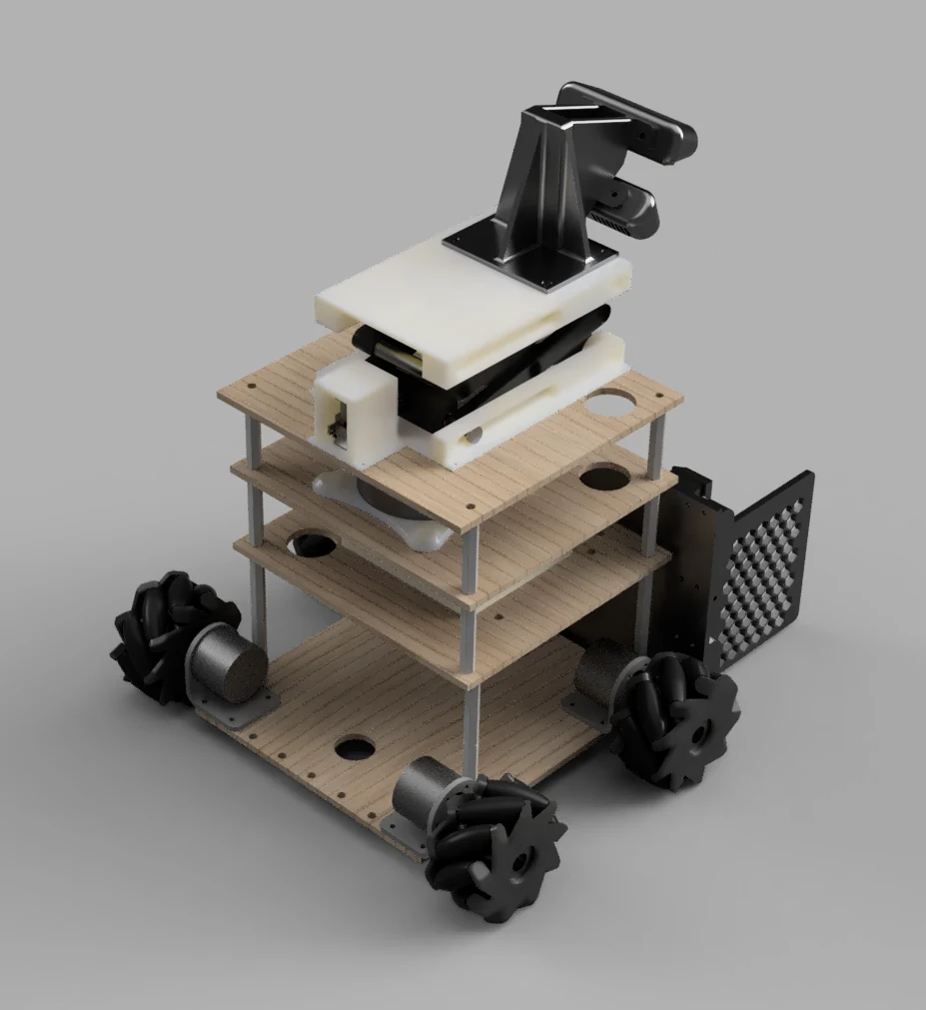
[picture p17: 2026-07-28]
media/renders/mast-down_iso_03.webp

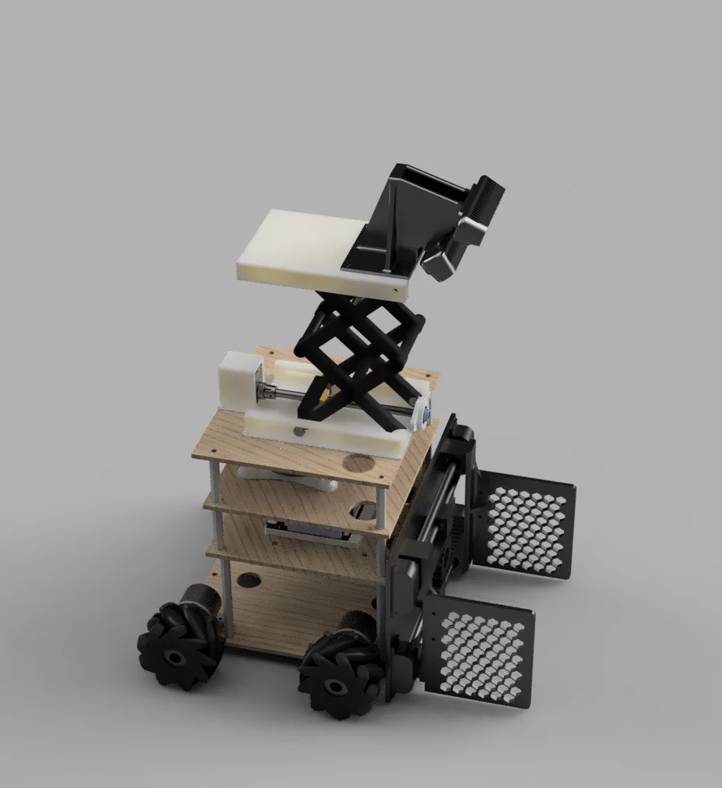
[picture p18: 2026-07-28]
media/renders/mast-up_iso_02.webp

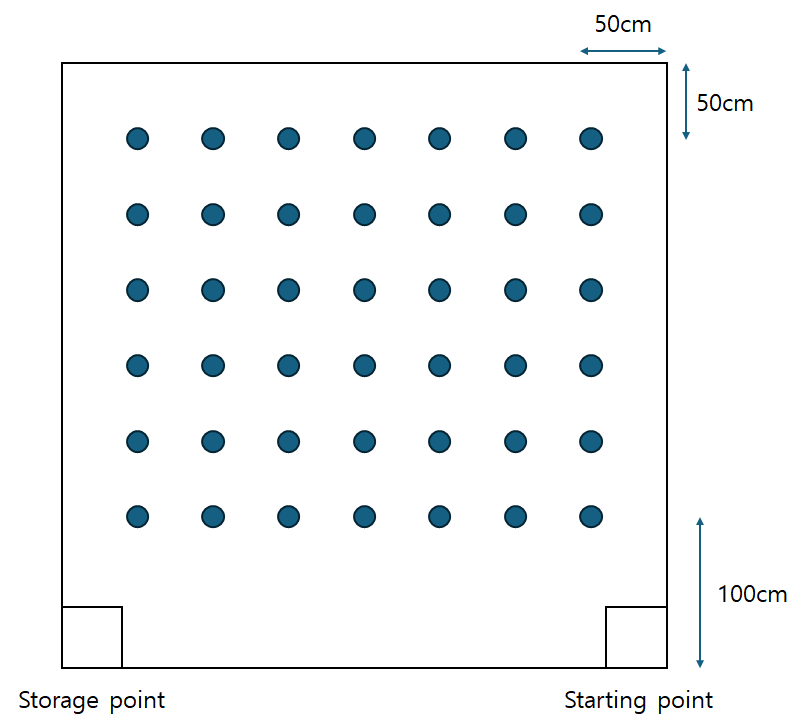
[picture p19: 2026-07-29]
docs/assets/arena-grid-official.png

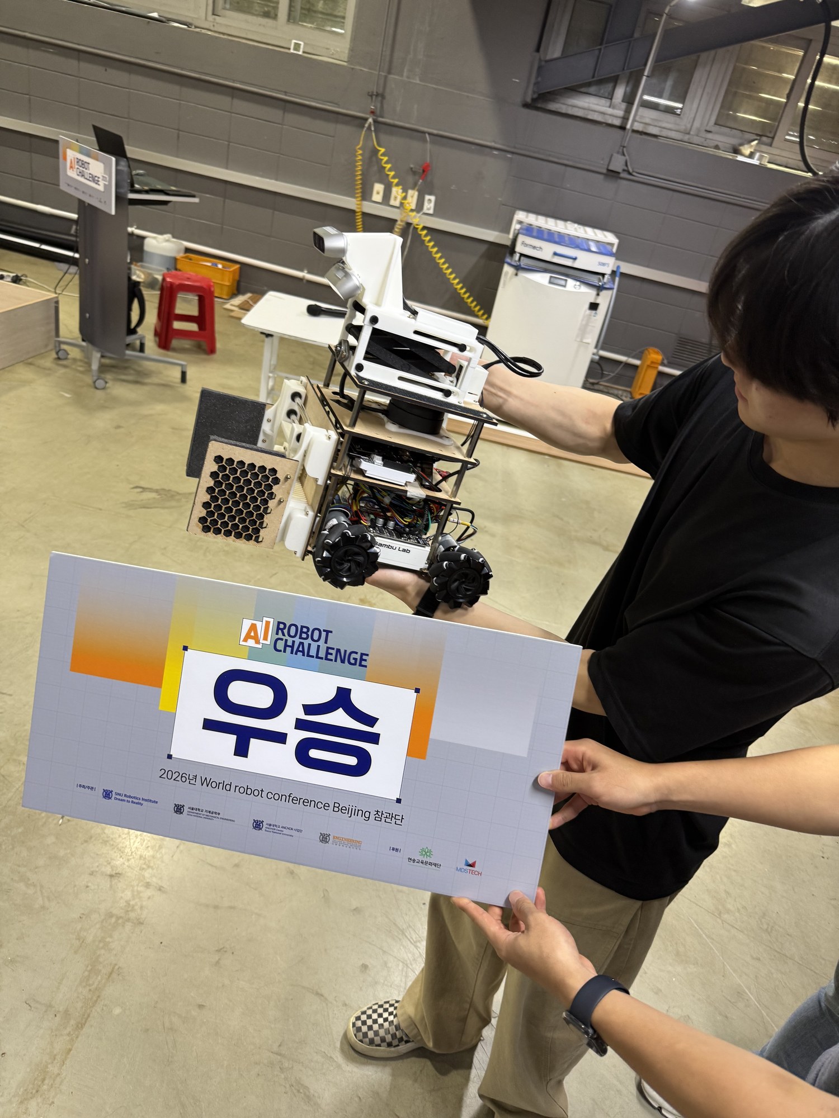
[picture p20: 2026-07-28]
media/award/award-with-robot.jpg

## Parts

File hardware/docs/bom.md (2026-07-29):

# Bill of materials — TEMPLATE

> ⚠️ **This is a template. Every "Approx cost" cell says `TODO` and must be filled in by the
> team.** The component list below is derived from the firmware, the ROS configuration, the
> URDF and the project's hardware notes, so the *parts* are accurate; the *prices* are not
> recorded anywhere in the repository and were never captured. Fill in currency, unit price
> and purchase date before treating this as a real BOM.
>
> Fields marked **(unverified)** are parts we can identify by family but not by exact model
> number from any file in the repository. Confirm against the physical robot before ordering.

Quantities are per robot. Cost column: enter unit price, and note the currency.

---

## Compute and control

| Component | Part | Qty | Notes | Approx cost |
|---|---|---:|---|---|
| Onboard computer | NVIDIA Jetson Orin Nano Developer Kit | 1 | Runs the entire ROS 2 Humble stack and both YOLO stages. All three microcontrollers and both cameras hang off its USB. Exact module variant (4 GB / 8 GB) **(unverified)** | TODO |
| Motion controller | Arduino UNO (R3) | 1 | 4 encoders, 50 Hz velocity PID, cascaded position loop. Firmware `hardware/firmware/arduino_mecanum/` | TODO |
| Servo controller | ROBOTIS OpenRB-150 | 1 | Gripper + camera mast on one Dynamixel bus. Firmware `hardware/firmware/openrb_gripper_mast/` | TODO |
| microSD / storage | — | 1 | For the Jetson **(unverified — size and type not recorded)** | TODO |

## Drivetrain

| Component | Part | Qty | Notes | Approx cost |
|---|---|---:|---|---|
| Gearmotor with encoder | JGB37-520, 12 V, 333 rpm, 1:30 gearbox, integrated quadrature hall encoder | 4 | 1320 counts/rev at the output shaft (11 PPR × 4 decode × 30). **All four must have encoders** — the position loop is per-wheel. No-load speed measured ≈ 34.9 rad/s at the wheel | TODO |
| Motor driver | Cytron MDD10A dual-channel | 2 | 2 channels each, 10 A continuous / 30 A peak per channel, 5–30 V motor supply, PWM + DIR sign-magnitude inputs, no EN/STBY pin. On-board test buttons are useful for pre-Arduino verification | TODO |
| Mecanum wheels | 80 mm diameter mecanum set (2 left-hand + 2 right-hand) | 4 | Must be mounted in **X configuration**. Effective contact radius fitted at 0.0388 m. A 68 mm set was also procured as a spare/alternative — the URDF generator supports both | TODO |
| Wheel hubs / couplers | 6 mm D-shaft hub to match the JGB37-520 output **(unverified)** | 4 | — | TODO |

## Sensors

| Component | Part | Qty | Notes | Approx cost |
|---|---|---:|---|---|
| Camera (top) | Intel RealSense D435 | 1 | Far/top view of the stitched pair. Rides the mast | TODO |
| Camera (near) | Intel RealSense D435i | 1 | Near/down view. **Its IMU is the robot's gyro** (`enable_bottom_imu`, remapped to `/imu/data`) — the localizer needs it to disambiguate the square arena's 90° symmetry | TODO |
| LiDAR | Slamtec RPLIDAR A2M12 | 1 | 256000 baud. Mounted at `base_link` z = 0.262 m with yaw = π (0° points to the robot's rear) | TODO |
| USB 3 cables | USB-C to USB-A/C, RealSense-grade | 2 | Two D435-class cameras on one Jetson need a custom `librealsense` RSUSB build — see `scripts/build_realsense_rsusb.sh` | TODO |

## Manipulator

| Component | Part | Qty | Notes | Approx cost |
|---|---|---:|---|---|
| Gripper servo | ROBOTIS Dynamixel XC330 (ID 0) | 1 | Current-based position mode, current limit 120 raw. Exact variant (e.g. XC330-M288 vs T288) **(unverified)** | TODO |
| Mast lift servo | ROBOTIS Dynamixel XC330 (ID 12) | 1 | Multi-turn, 31641-tick (148.9 mm) stroke, ~7.7 turns. Exact variant **(unverified)** | TODO |
| Dynamixel cables | 3-pin JST (X-series) | 2+ | Daisy-chained: OpenRB → ID 0 → ID 12 | TODO |
| Parallel gripper mechanism | Custom — jaws, linkage, servo horn | 1 set | 0–70 mm reported jaw span. Source CAD is not published | TODO |
| Camera mast + lift | Custom — vertical rail/lead-screw assembly carrying both cameras | 1 set | 148.9 mm measured stroke; the top bracket sags ~0.95° when raised, which the perception calibration models | TODO |

## Power and wiring

| Component | Part | Qty | Notes | Approx cost |
|---|---|---:|---|---|
| Battery | 12 V pack | 1 | Chemistry and capacity **not recorded anywhere in the repository** — fill in from the physical robot | TODO |
| Jetson power | Regulator / dedicated supply for the Jetson **(unverified)** | 1 | The Jetson is not powered from the 12 V motor rail in any documented way | TODO |
| Main power switch / fuse | Kill switch on the 12 V rail | 1 | Rating and fusing **(unverified — not documented)**. Operationally it is load-bearing: the Jetson must boot with this switch **off**, or the OpenRB-150 does not enumerate reliably ([wiring-and-firmware.md](wiring-and-firmware.md#boot-the-jetson-with-the-12-v-kill-switch-off)) | TODO |
| Power distribution | Battery → 2 × MDD10A VM in parallel; common ground bus | 1 set | **Common ground is mandatory**: battery ↔ both MDD10A ↔ Arduino ↔ Jetson (via USB). A missing common ground was the suspected cause of a 2026-06-26 motor fault. Check branch-wire gauge and connector rating against the stall current | TODO |
| Motor / power connectors | XT60 or equivalent **(unverified)** | — | — | TODO |
| Encoder wiring | 4-conductor per motor (A, B, 5 V, GND) | 4 | Encoder VCC comes from the **Arduino 5 V rail**, never from motor power | TODO |
| USB cables | Arduino UNO (USB-B), OpenRB-150 (USB **(unverified connector)**), RPLIDAR | 3 | — | TODO |
| Powered USB hub | Self-powered, for the UNO and the OpenRB-150 | 1 | Not optional in practice: both boards dropped their ttys intermittently when plugged straight into the Orin Nano, and were noticeably more stable behind the hub ([wiring-and-firmware.md §2](wiring-and-firmware.md#2-boards-buses-and-who-owns-what)). Its port topology is what the default `by-path` device paths encode | TODO |

## Structure

| Component | Part | Qty | Notes | Approx cost |
|---|---|---:|---|---|
| Lower deck plate | 190 × 250 × 6 mm | 1 | Height 0.173 m above ground (URDF collision box) | TODO |
| Middle deck plate | 190 × 210 × 6 mm | 1 | Height 0.258 m | TODO |
| Upper deck plate | 190 × 170 × 6 mm | 1 | Height 0.333 m | TODO |
| Front / side panels | see URDF collision boxes | — | `hardware/cad/urdf/robot_mk3_mecanum_sim_80mm.urdf` | TODO |
| Standoffs, brackets, fasteners | M3 assortment **(unverified)** | — | — | TODO |
| Motor mounts | JGB37-520 brackets | 4 | — | TODO |

Modelled chassis mass is 2.4 kg (simulation value in the URDF, not a weighed figure).

## Tools and consumables for bring-up

| Item | Why | Approx cost |
|---|---|---|
| Blocks / stand to lift the wheels clear of the floor | Bring-up steps 10–30 must run with the wheels free | TODO |
| Tape measure and masking tape | Effective wheel radius and rotation geometry are fitted against measured travel | TODO |
| `arduino-cli` with the `arduino:avr` core | `hardware/bringup_tools/00_flash_firmware.sh` | free |
| ROBOTIS DYNAMIXEL Wizard 2.0 | Used to measure the gripper's closed/open angles (36.74° / 214.37°, 2026-07-16) | free |

---

## Notes for whoever fills this in

1. Add a currency and a date column — component prices for this class of parts moved
   noticeably during 2026.
2. Record the **exact** XC330 variant and the battery specification from the physical robot;
   they are the two most consequential unknowns in this list.
3. The Fusion 360 source CAD is not published. `hardware/cad/meshes/` and the URDF
   carry the geometry the code actually uses; the mechanical parts would have to be
   remodelled from those and from the dimensions in this list.
4. If you substitute the motor driver, check §5 of
   [`wiring-and-firmware.md`](wiring-and-firmware.md#5-motor-driver-wiring-cytron-mdd10a--2)
   first: the firmware supports both sign-magnitude and inverted-PWM drivers, but only via
   the runtime `mstyle` command, and the shipped defaults assume MDD10A.

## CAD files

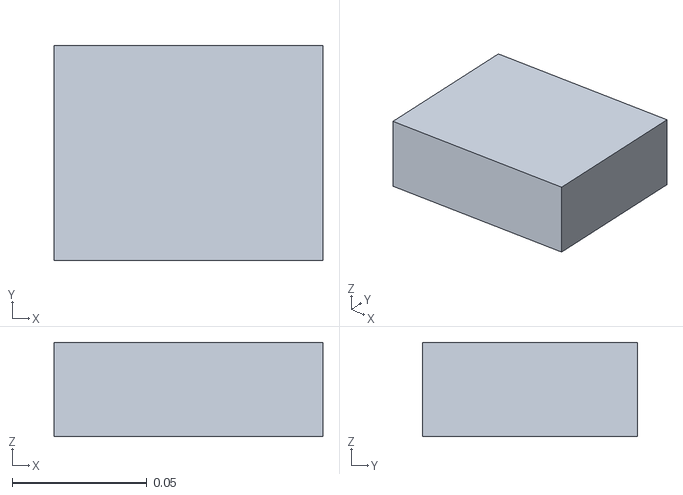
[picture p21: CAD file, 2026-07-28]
hardware/cad/meshes/jetson_orin_nano.stl
0.1 x 0.08 x 0.035

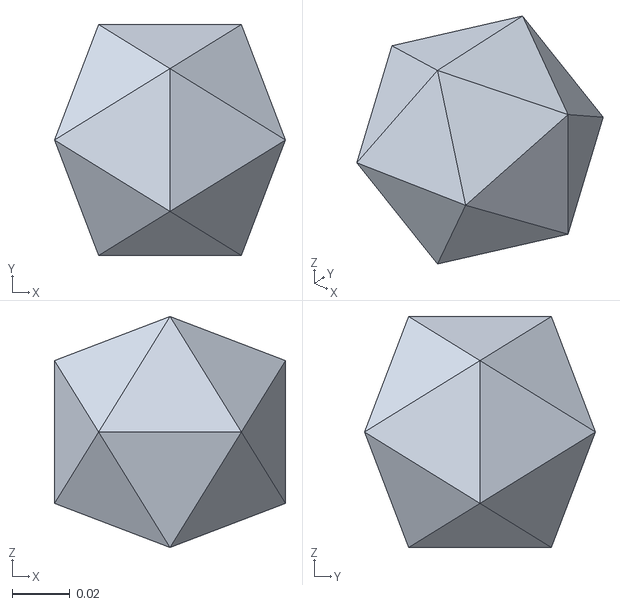
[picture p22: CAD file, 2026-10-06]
perception/generation/assets/generated/icosahedron.obj
0.08 x 0.08 x 0.08

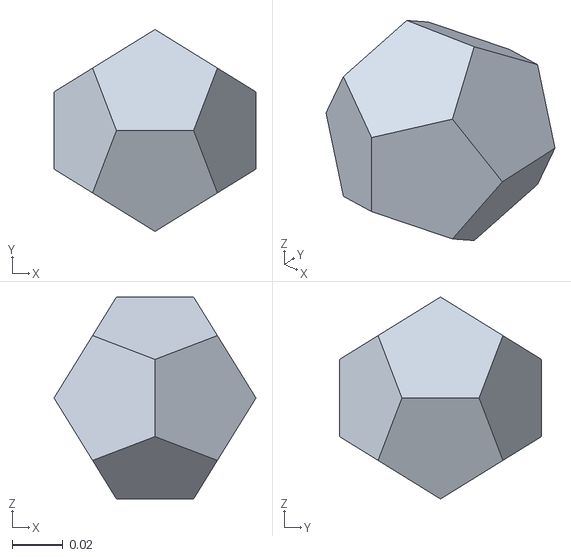
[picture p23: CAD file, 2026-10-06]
perception/generation/history/upstream/assets/generated/dodecahedron.obj
0.08 x 0.08 x 0.08

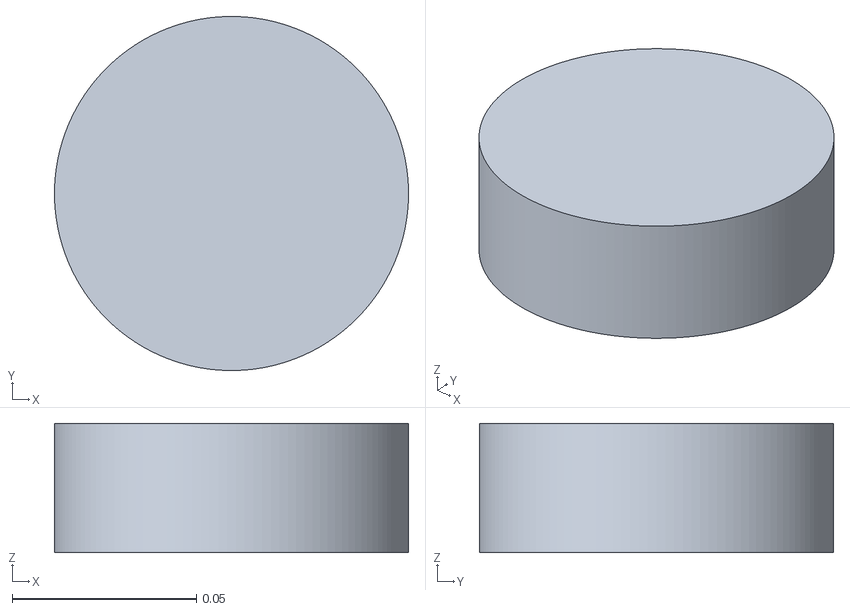
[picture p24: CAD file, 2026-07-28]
hardware/cad/meshes/lidar.stl
0.096 x 0.096 x 0.035

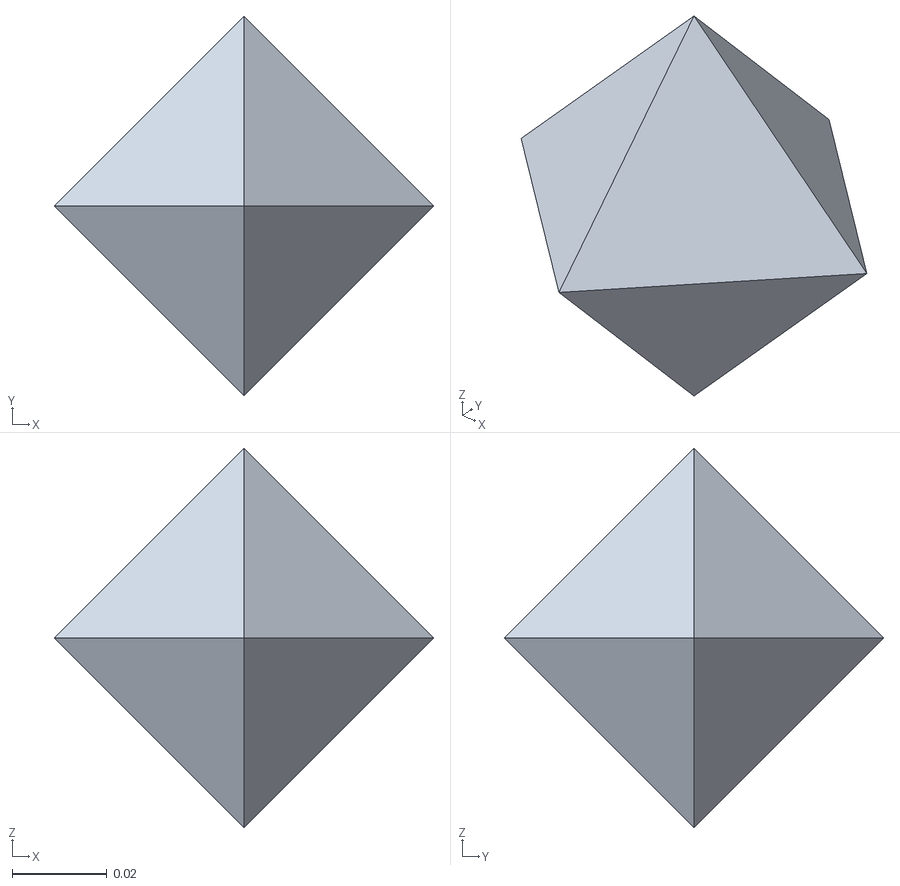
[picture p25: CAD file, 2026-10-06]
perception/generation/assets/generated/octahedron.obj
0.08 x 0.08 x 0.08

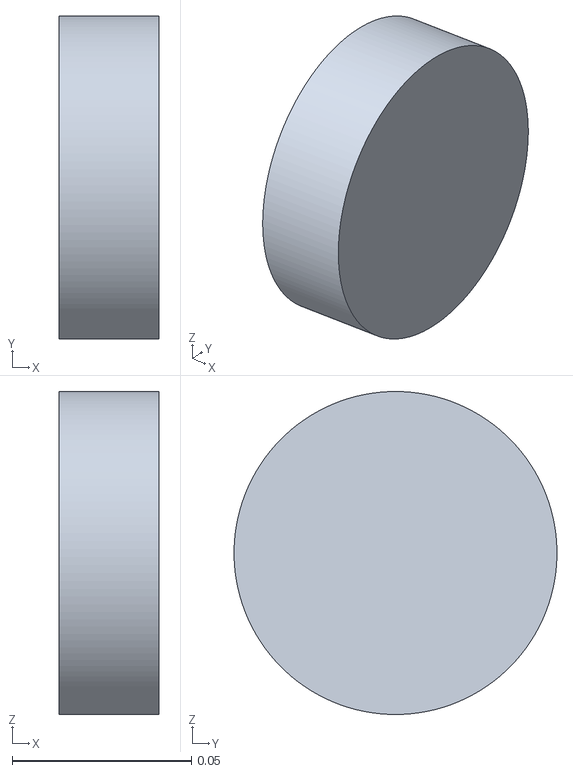
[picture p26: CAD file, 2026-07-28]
hardware/cad/meshes/left_wheel.stl
0.028 x 0.09 x 0.09

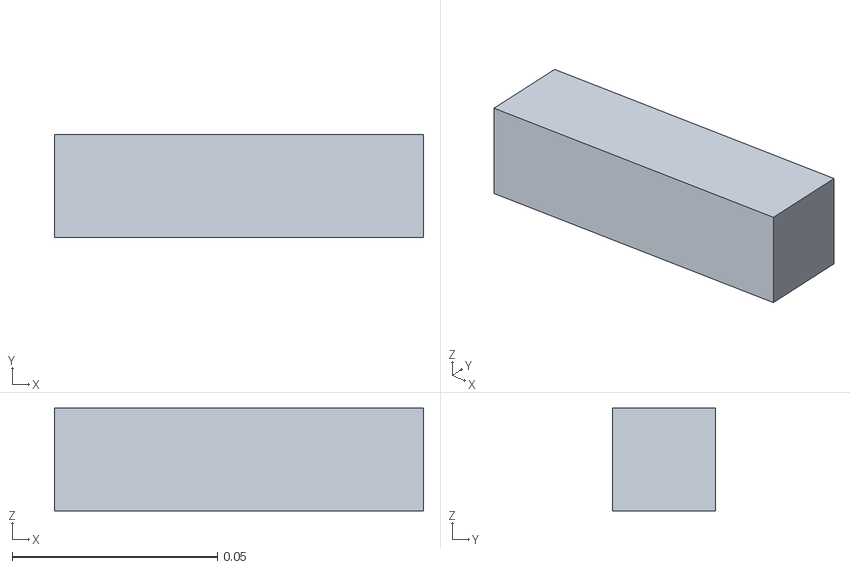
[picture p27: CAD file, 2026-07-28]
hardware/cad/meshes/near_d435i.stl
0.09 x 0.025 x 0.025

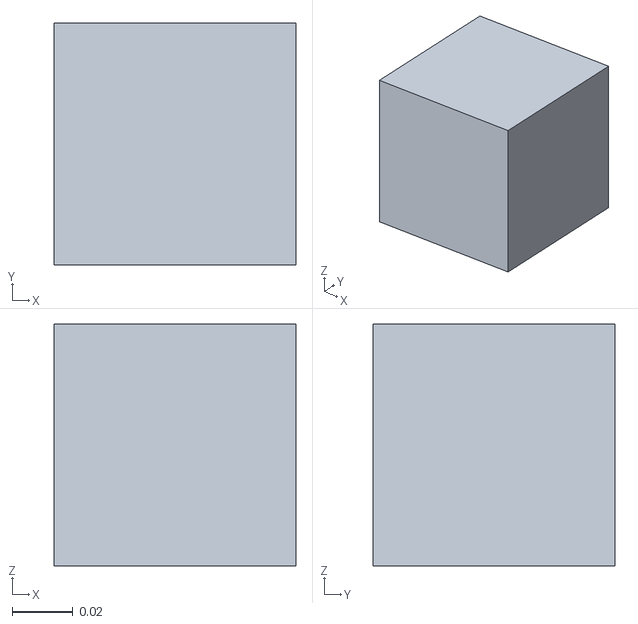
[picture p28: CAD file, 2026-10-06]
perception/generation/assets/generated/plain_cube.obj
0.08 x 0.08 x 0.08

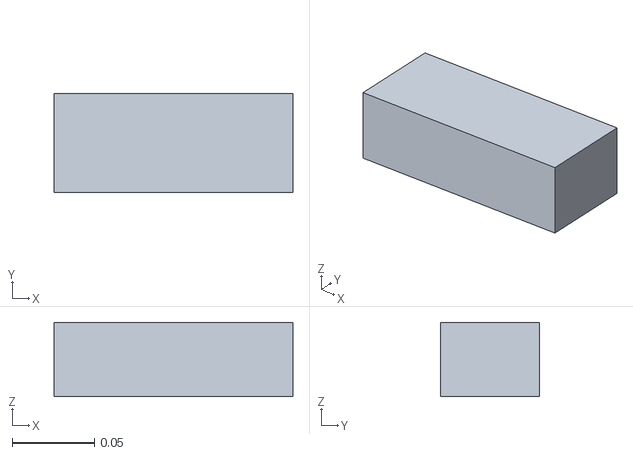
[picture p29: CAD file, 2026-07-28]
hardware/cad/meshes/battery.stl
0.145 x 0.06 x 0.045

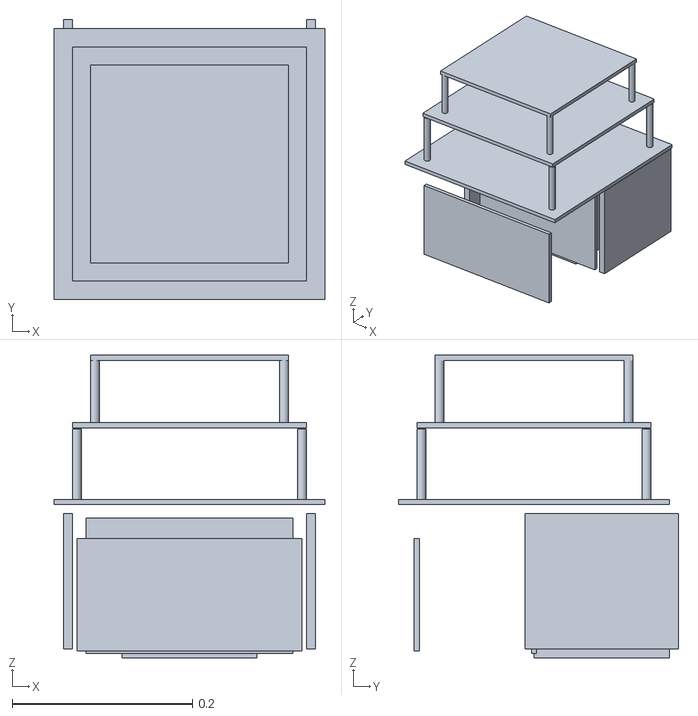
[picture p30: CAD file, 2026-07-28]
hardware/cad/meshes/base_link.stl
0.3 x 0.31 x 0.336

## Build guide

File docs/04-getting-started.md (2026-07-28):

# 04 — Getting Started

Install, build, and run the stack: on a Linux workstation for the offline parts, and on a
Jetson Orin Nano for the real robot.

Read [`docs/08-reproducibility.md`](08-reproducibility.md) alongside this page. Several things
in this repository are **hardware- and venue-specific by construction** and cannot be copied
into a different setup — §9 below lists them explicitly. If you skip that section you will
get a stack that builds, launches, and then misjudges every object position.

---

## 1. Supported platform

| | Workstation (offline) | Robot (onboard) |
|---|---|---|
| OS | Ubuntu 22.04 | Ubuntu 22.04 (JetPack 6, L4T) |
| ROS 2 | Humble | Humble |
| Python | 3.10 | 3.10 |
| Compute | any x86-64 + NVIDIA GPU (optional) | Jetson Orin Nano 8 GB |
| What you can do | build, run the unit tests, run the 2-stage perception pipeline on saved images, train, Isaac Sim | everything, plus drive the real robot |

ROS 2 Humble is the only supported distribution. The launch scripts accept `jazzy` as an
explicit opt-in argument but nothing here was run on Jazzy.

---

## 2. System packages

```bash
sudo apt update
sudo apt install -y \
  git-lfs \
  python3-colcon-common-extensions \
  python3-pip \
  python3-serial \
  ros-humble-realsense2-camera \
  ros-humble-tf2-ros \
  ros-humble-vision-msgs
```

`ros-humble-realsense2-camera` is only needed on the robot. Everything else is needed on
both machines.

### LiDAR device symlink

The bringup opens the RPLIDAR at `/dev/rplidar`
(`hardware/ros2/robot_bringup/launch/real_competition_bridge.launch.py:192`). That name comes
from a udev rule shipped with the vendored driver:

```bash
sudo cp third_party/sllidar_ros2/scripts/rplidar.rules /etc/udev/rules.d/
sudo service udev reload && sudo service udev restart
# replug the LiDAR, then:
ls -l /dev/rplidar
```

### Two RealSense cameras on one Jetson

Two D435-class cameras on a single Orin Nano do not reliably enumerate on the stock kernel
UVC backend. The competition robot ran the **RSUSB** (userspace libusb) backend for the
bottom camera. Build it once:

```bash
scripts/build_realsense_rsusb.sh          # librealsense v2.58.2, FORCE_RSUSB_BACKEND=ON
```

It installs to `~/.local/opt/librealsense-rsusb-2.58.2/`. `scripts/run_real_competition_bridge.sh`
picks it up automatically when present; set `USE_REALSENSE_RSUSB=false` to disable.

---

## 3. Clone the repository

Install `git-lfs` **before** cloning — the simulation USD scenes, the STL visual meshes and the
map PGM are LFS objects.

```bash
git lfs install
git clone <this-repo-url> ddonggae
cd ddonggae
git lfs pull
```

Check that no LFS object is still a ~130-byte pointer file:

```bash
find simulation/usd hardware/cad/meshes -type f -size -1k -print
```

---

## 4. Python dependencies

```bash
pip install --user numpy opencv-python ultralytics onnxruntime pyserial pillow
```

| Package | Used by | Note |
|---|---|---|
| `numpy` | everything | |
| `opencv-python` | stitching, calibration tools, crops | headless hosts can use `opencv-python-headless` |
| `ultralytics` | both YOLO stages | **8.4.54** on the training host, **8.4.21** on the Jetson. No divergence was ever reproduced between them, but keep it on the list of suspects when comparing results across machines. |
| `onnxruntime` | the two pair verifiers (`perception/models/verifiers/*.onnx`) | if it is missing, the pair route degrades to `off` automatically |
| `pyserial` | motor / gripper bridges | also available as the apt package `python3-serial` |
| `pillow` | depth PNG I/O (`uint16` mm, PIL mode `I;16`) | |

`torch` / `torchvision` are only needed for **training** (`perception/training/`), not for
running a match — `ultralytics` pulls in a suitable torch when you install it.

If a pinned `requirements.txt` is present at the repository root, prefer
`pip install -r requirements.txt` over the loose install above.

---

## 5. Model weights

The weights are **not in git**. They are published as GitHub Release assets so that a plain
clone stays small, and because they are Ultralytics YOLO derivatives with different licensing
terms from this repository (see `NOTICE`).

```bash
scripts/fetch_models.sh
```

This downloads the published weights into `perception/models/` and verifies them against the published
`SHA256SUMS`:

| Path | Role | Size |
|---|---|---|
| `perception/models/a1_objectseg/best.pt` | stage A1 — full-frame object segmentation (`cube_like_object`, `octahedron`, `dodecahedron`, `icosahedron`) | 23.4 MB |
| `perception/models/unified_face/best.pt` | stage 2 — cube face identity (`apple`, `orange`, `banana`, `pineapple`, `plain`) | 23.3 MB |
| `perception/models/verifiers/pair_apple_orange_v2.onnx` | binary apple-vs-orange second opinion | 6.1 MB |
| `perception/models/verifiers/pair_banana_pineapple_v2.onnx` | binary banana-vs-pineapple second opinion | 6.1 MB |

Override the source with `GH_REPO=<owner/repo>` and `RELEASE=<tag>`.

Two runtime contracts are wired into the code and must not be "cleaned up". Both were found
by losing accuracy to them:

- **The face model must run at `imgsz=224`** (`perception/fieldlib.py:68`). It was trained at
  224. Passing `imgsz=640` collapses face confidence from ~0.9 to 0.1–0.4 and mis-classifies
  fruit faces. The safest call is to not pass `imgsz` at all and let Ultralytics use the
  checkpoint's training value. Stage A1 is the opposite: it was trained at 640 and runs at
  **896** on the stitched frame (`perception/fieldlib.py:67`), because the stitched frame is
  ~890 px tall and 640 would downscale it by 0.72x.
- **The face model must receive BGR numpy arrays** — the `cv2.imread` convention that
  Ultralytics assumes. Feeding a PIL-read RGB array flips `orange`↔`plain` and
  `apple`↔`pineapple` in measurements. If you are on a PIL path, convert with
  `arr[:, :, ::-1]`.

The face model started from the synthetic-render training set described in
[`perception/docs/synthetic-data.md`](../perception/docs/synthetic-data.md) and was fine-tuned
on real arena photographs on 2026-07-24.

---

## 6. Build the ROS 2 workspace

The ROS 2 packages are **not** in a single `src/` directory. They live next to the subsystem
they belong to:

| Package | Location | Type |
|---|---|---|
| `robot_hardware` | `hardware/ros2/robot_hardware` | ament_python |
| `robot_bringup` | `hardware/ros2/robot_bringup` | ament_python |
| `arena_lightweight_control` | `navigation/ros2/arena_lightweight_control` | ament_python |
| `sllidar_ros2` | `third_party/sllidar_ros2` | ament_cmake |

`colcon` discovers packages recursively under every directory given to `--base-paths`, so one
invocation covers all four:

```bash
source /opt/ros/humble/setup.bash
colcon build --symlink-install \
  --base-paths hardware/ros2 navigation/ros2 third_party
source install/setup.bash
```

Verify before building, if you want to see what will be picked up:

```bash
colcon list --base-paths hardware/ros2 navigation/ros2 third_party
# arena_lightweight_control  navigation/ros2/arena_lightweight_control  (ros.ament_python)
# robot_bringup              hardware/ros2/robot_bringup                (ros.ament_python)
# robot_hardware             hardware/ros2/robot_hardware               (ros.ament_python)
# sllidar_ros2               third_party/sllidar_ros2                   (ros.ament_cmake)
```

A clean build of all four takes about 11 s on a desktop; `sllidar_ros2` is the only C++
package and emits compiler warnings from the vendored Slamtec SDK — those are expected.

To avoid typing `--base-paths` every time, put a `colcon_defaults.yaml` at the repository
root:

```yaml
build:
  base-paths: [hardware/ros2, navigation/ros2, third_party]
  symlink-install: true
```

### `rosdep` does not work here

`hardware/ros2/robot_bringup/package.xml` still declares `exec_depend` entries for five
packages that were part of the original private workspace and are **not** in this public
release: `example_nav2`, `robot_description`, `robot_perception`, `robot_semantic_mapping`,
`robot_task_planner`. `colcon build` is unaffected (they are runtime, not build, dependencies
and nothing in the shipped launch files instantiates them), but `rosdep install --from-paths`
will fail on them. Install the apt dependencies from §2 by hand instead.

---

## 7. Run the tests

The unit tests are the parts of the stack that need no robot and no GPU: mecanum kinematics
and odometry, wall-range localisation, the goal-latch controllers, the stitch geometry
contract, the grasp fine-alignment maths, and the web UI handlers.

```bash
source install/setup.bash                       # puts the ament_python packages on PYTHONPATH
PYTHONPATH="$PWD/perception:$PYTHONPATH" python3 -m pytest tests/ -q
```

`perception/` has to be added by hand because `fieldlib.py` and `geometry.py` are plain
modules, not a ROS package — they are deliberately importable without an ROS environment so
that the perception contract can be tested and reused off-robot.

---

## 8. Run the bringup

Everything below assumes the robot: motors powered, kill switch on, LiDAR and both cameras
plugged in, and the robot physically placed in the start zone.

### 8.1 One launch for the whole stack

`lightweight_real.launch.py` includes the hardware bridge by default
(`launch_bridge:=true`), so a single launch brings up cameras, LiDAR + scan watchdog, the
`cmd_vel` mux, the motor bridge, the gripper/mast bridge, and the arena localisation and
control node.

```bash
source /opt/ros/humble/setup.bash
source install/setup.bash

ros2 launch arena_lightweight_control lightweight_real.launch.py \
  launch_bridge:=true \
  launch_cameras:=true \
  drive_type:=mecanum \
  controller_type:=mecanum \
  base_scan_yaw:=0.0 \
  imu_topic:=/imu/data \
  enable_web_ui:=true \
  launch_python_ui:=false \
  map_yaml:=$PWD/navigation/ros2/arena_lightweight_control/maps/stadium.yaml
```

Four of those arguments are not optional in practice:

- **`drive_type` / `controller_type`** default to `diff` / `diff_drive`. The competition robot
  is mecanum. Setting only one of the two silently gives you a mismatched pair
  (a diff-drive bridge fed by a mecanum controller, or the reverse).
- **`base_scan_yaw`** is the LiDAR mount yaw. The launch default is `3.14159265359`
  (`real_competition_bridge.launch.py:210`), which was correct for the earlier MK3 mount; the
  field automation used **`0.0`** for the mecanum build
  (`perception/fieldlib.py`, `BridgeManager.launch_stack`). Measure yours with
  `hardware/bringup_tools/40_lidar_orientation_check.py` before trusting either.
- **`map_yaml`** must be passed explicitly. Its default still resolves through
  `FindPackageShare("example_nav2")`
  (`navigation/ros2/arena_lightweight_control/launch/lightweight_real.launch.py:39-44`), and
  that package is not part of this release; the map moved to
  `navigation/ros2/arena_lightweight_control/maps/`. Without the override the launch aborts.

The web UI is then at `http://<robot-ip>:18765` — a map view with click-to-goal, used by the
operator for setup and debugging, never during a scored run.

### 8.2 The operator wrapper

`scripts/run_lightweight_arena_control.sh` and `scripts/run_real_competition_bridge.sh` are
the wrappers that were actually typed in the field. On top of the launch they:

- clean up orphaned bridge processes before starting (a stale `motor_bridge_node` sharing the
  Arduino's tty with a fresh `mecanum_bridge_node` corrupts the firmware's command parser — a
  2026-07-18 field incident that needed a physical USB replug to recover);
- select the RSUSB librealsense prefix if it was built;
- scrub `AMENT_PREFIX_PATH` / `PYTHONPATH` of other ROS distributions before sourcing.

They read the same knobs as environment variables (`DRIVE_TYPE`, `BASE_SCAN_YAW`,
`LAUNCH_CAMERAS`, `IMU_TOPIC`, `UI_PORT`, `GRIPPER_SERIAL_PORT`, …). Check the paths inside
them against your own checkout before use.

### 8.3 Check that the stack is alive

```bash
python3 mission/field_autopilot.py check
```

This subscribes for 8 s and prints a pass/fail line per contract topic: LiDAR scan, arena
status, wheel odometry, IMU, all four camera streams, gripper/mast board liveness, and the
localisation lock. Exit code `0` means everything required is present, `2` means something
required is missing. `field_autopilot.py up` does the same but launches the stack first and
seeds the start pose; `field_autopilot.py down` stops everything and reports leftovers.

---

## 9. Run a match

`mission/match_runner.py` is the competition state machine: seed pose → raise mast → drive to
the scan point → 12-way stitched scan → snap detections onto the 42-cell grid → for each target
{route, approach, measure, grasp, carry, place} → repeat until the object budget or the
3-minute clock runs out.

Start conservatively:

```bash
# offline: argument, GT-parsing and router self-test, no ROS needed
python3 mission/match_runner.py --offline

# first real run: pick exactly one object, do not place it
python3 mission/match_runner.py \
  --gt-text "apple:150,200;plain:250,300;octahedron:100,150" \
  --max-objects 1 --no-place --speed-profile safe

# full run in competition mode
python3 mission/match_runner.py \
  --target-shape icosahedron --target-fruit apple \
  --order fruit-first --speed-profile normal
```

Notable arguments:

| Argument | Meaning |
|---|---|
| `--gt-text` / `--gt-file` | the operator types the true object layout in official cm coordinates (`cls:x,y;…`). The runner prints a correct/wrong/ghost/missed table right after the scan, so a bad scan is caught **before** the robot drives anywhere. |
| `--target-shape` / `--target-fruit` | competition mode: set 1 is a polyhedron shape (10 pts x4), set 2 is a fruit face (20 pts x3). Announced on the day. |
| `--order` | `nearest` \| `fruit-first` \| `shape-first` |
| `--speed-profile` | `safe` (0.5 / 0.4 / 0.3 m/s drive/approach/place), `normal` (0.8 / 0.6 / 0.4), `fast` (0.95 / 0.7 / 0.45 — 95 % of the measured ~1.0 m/s ceiling) |
| `--pair on\|off\|ao\|bp` | which binary pair verifiers give a second opinion on fruit faces. Default `bp`: banana/pineapple only. Both finals ran `bp`; qualifier 1 ran `on` and qualifier 2 `ao`. Auto-off if the ONNX files are missing |
| `--range-mode depth\|ground` | `depth` (default) measures the target from the aligned depth image; `ground` back-projects the silhouette's bottom edge through the floor plane. `ground` over-estimates range by 27–64 mm for objects whose visible face is 4–7 cm above the floor — that bias cost 0/4 icosahedron grasps on 2026-07-20 and is why `depth` is the default. |
| `--dry-run` | run scan and inference, log motion/gripper commands instead of sending them |

Outputs land in `logs/field_ops/<timestamp>_e2e/`: `report.json` (per-cycle phase timings,
measurement attempts, grasp verdicts), `grid_map.json`, `gt.json`, the raw top/near RGB+depth
pairs, and the annotated stitched debug frames.

---

## 10. What cannot be reproduced as-is

This is the honest part. Four classes of artefact in this repository are tied to *our*
hardware and *our* venue, and copying the numbers will actively hurt you.

### 10.1 TensorRT engines — not shipped, not portable

The Jetson ran a TensorRT engine for stage A1
(`a1_yolo26s_seg_896_fp16.engine`) when one was present next to the `.pt`, and fell back to
the `.pt` otherwise. Engines are serialised against one specific TensorRT version, CUDA
version, and GPU architecture; an engine built on our JetPack will not load on yours. None
are distributed. Either build your own on the target device from
`perception/models/a1_objectseg/best.pt`, or just run the `.pt` — the pipeline works either
way, only slower.

### 10.2 Device paths and camera serials — machine-specific

| Constant | Value | Where |
|---|---|---|
| Top camera serial | `_030422070364` | `real_competition_bridge.launch.py:152` |
| Bottom camera serial | `_112322074553` | `real_competition_bridge.launch.py:153` |
| Gripper/mast board | `/dev/serial/by-id/usb-ROBOTIS_OpenRB-150*-if00` (was by-path until the board swap on 07-23) | `~~/dev/serial/by-path/platform-3610000.usb-usb-0:2.3.3:1.0` | `real_competition_bridge.launch.py:146-147` |
| Arduino (motors) | `/dev/serial/by-id/usb-Arduino__www.arduino.cc__Arduino_14101-if00` | `hardware/ros2/robot_bringup/config/real.yaml:3-4` |
| LiDAR | `/dev/rplidar` | udev symlink, §2 |

The serial numbers identify *our* two cameras. The `by-path` string encodes the Orin Nano's
USB topology (`platform-3610000.usb`) **and the physical port the board is plugged into** —
move the cable and it changes. `real.yaml` carries a `serial_port_candidates` list precisely
because a single fixed path was not reliable. Find yours with
`rs-enumerate-devices` and `ls -l /dev/serial/by-id /dev/serial/by-path`, then override the
launch arguments.

### 10.3 Stitch calibration — must be re-measured on your robot

`perception/calibration/stitch/{up,down}.json` hold a 3x3 near→top pixel transform fitted at
1920x1080 for two specific cameras on one specific mast, at two specific mast heights
(inlier RMS 0.78 px for `up`, 1.13 px for `down`). It encodes the *relative pose of your two
camera brackets*. There is nothing generic about it.

Re-fit it with the browser calibrator:

```bash
python3 perception/tools/stitch_calibrator.py --mast up     # then open http://<robot>:8099/
```

Two lessons are baked into that tool. The original parameters were fitted from **one**
correspondence point, which fixes translation only and constrains neither scale (field of
view) nor roll — the classic "centre lines up, both edges splay apart" symptom, measured here
as a 0.53° roll error. And the overlap band is only ~70 rows tall, which is too little
vertical spread to constrain a homography: fitting one made the corners diverge by 330 px, so
`fit_A` now refuses affine/homography when the point spread is insufficient and falls back to
a similarity fit. Put your correspondence points across the **full width** of the band, and
use a flat target — the two cameras sit at different heights, so anything raised off the
floor cannot be aligned by any 2D transform.

### 10.4 Venue photometry — must be re-measured at your venue

Auto-exposure must be **locked**, because two free-running cameras converge to different
exposures and split the seam. The right value depends entirely on the room's lighting.

| Setting | Value | Where |
|---|---|---|
| Exposure | 320 | `real_competition_bridge.launch.py:176` |
| Gain | 64 | `real_competition_bridge.launch.py:177` |
| White balance | 6300.0 K | `real_competition_bridge.launch.py:171` |
| Recorded arena sweep, 2026-07-20 | exposure 200 / gain 64 / WB 4600 K, `pass: false` | `perception/calibration/photometry/arena.json` |

Re-measure at your venue, with the mast **up** (measuring with the mast down inflates the
seam metrics several-fold — the down-position overlap band is 29 rows of extreme lens edge,
where vignetting and specular reflection dominate: ΔY 28 down vs ΔY 6 up):

```bash
ros2 topic pub --once /lift/command std_msgs/String "{data: LIFT_TO_TOP}"
python3 perception/tools/photometry_tune.py --check    # ~8 s diagnosis
python3 perception/tools/photometry_tune.py --sweep    # ~1 min, prints the launch arguments
```

Acceptance: floor luma Y in 100–140, |ΔY| ≤ 6 across the seam, |ΔR/G| ≤ 0.05, |ΔB/G| ≤ 0.05,
and no blown-out white objects. One caveat we measured and you will hit too: the residual
colour difference between the two cameras is **sensor-to-sensor** (D435 vs D435i) and white
balance does not fix it — sweeping WB from 3200 K to 6000 K moved ΔR/G by 0.004. Treat the
colour deltas as informational.

### 10.5 Camera mount geometry

`TOP_MOUNT_*` / `NEAR_MOUNT_*` in `perception/fieldlib.py:41-52` are measured mount poses
(forward offset, height, tilt) for three mast positions, fitted against depth floor-plane
measurements and cross-checked with a tape measure. Two honest caveats are recorded in the
source and repeated here: `forward_m` has never been measured by any calibration (plane
fitting cannot observe it), and mount roll (−1.0° to −2.5°) is not modelled by
`pixel_to_ground` at all, so lateral error of a few cm is possible at the frame edges.

---

## Where to go next

| You want to | Read |
|---|---|
| Understand what the robot is answering to | [`01-competition-and-rules.md`](01-competition-and-rules.md) |
| Understand how the pieces fit | [`02-architecture.md`](02-architecture.md) |
| Know the exact topics and message contracts | [`03-ros2-interfaces.md`](03-ros2-interfaces.md) |
| Run a competition day end to end | [`05-field-runbook.md`](05-field-runbook.md) |
| Fix something that is broken | [`06-troubleshooting.md`](06-troubleshooting.md) |
| See what actually happened, including what failed | [`07-results-and-lessons.md`](07-results-and-lessons.md) |

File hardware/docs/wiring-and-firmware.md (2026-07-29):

# Wiring and firmware

Everything between the battery and the ROS graph: pin map, motor driver, encoder wiring,
the complete serial protocol for both microcontrollers, the two-level PID cascade, and the
motion primitives the firmware owns.

---

## 1. Which sketches are the flashed competition firmware

| Board | Sketch | Status |
|---|---|---|
| Arduino UNO | `hardware/firmware/arduino_mecanum/mecanum_encoder_control.ino` | **Flashed for the competition.** Last modified 2026-07-17. Its serial grammar matches `mecanum_control.py`'s parsers and `mecanum_bridge_node.push_firmware_config()` exactly. |
| OpenRB-150 | `hardware/firmware/openrb_gripper_mast/openrb_gripper.ino` | **Flashed for the competition.** Last modified 2026-07-17. Every string `gripper_bridge_node` writes or parses is implemented here. |

Three earlier Arduino sketches from the project history (`mecanum_pwm_control` open-loop,
`encoder_pwm_test` differential-drive, `sketch_may21a` bring-up demo) are **not** published:
they are superseded and their pin maps contradict the shipped wiring.

Flashing:

```bash
bash hardware/bringup_tools/00_flash_firmware.sh          # arduino-cli, fqbn arduino:avr:uno
```

Stop `mecanum_bridge_node` first — it holds the port with `exclusive=True` (see §8.4). The
OpenRB sketch is uploaded from the Arduino IDE / `arduino-cli` with the OpenRB-150 board
package and needs the ROBOTIS `Dynamixel2Arduino` library from the Library Manager (the
project vendored it; this repository does not).

---

## 2. Boards, buses, and who owns what

| Bus | Device | Baud | Owner process |
|---|---|---|---|
| USB CDC → Arduino UNO | 4 × motor, 4 × encoder | 115200, 8N1, line-oriented | `mecanum_bridge_node` (exclusive lock) |
| USB CDC → OpenRB-150 | gripper + mast | 115200 | `gripper_bridge_node` (**sole owner** — see [gripper-and-mast.md](gripper-and-mast.md#5-one-process-owns-the-tty)) |
| OpenRB `Serial1` → Dynamixel | XC330 ID 0 (gripper), ID 12 (mast) | 1 000 000, Protocol 2.0 | OpenRB firmware |
| USB → RPLIDAR A2M12 | LiDAR | 256000 | `sllidar_node` |
| USB3 → 2 × RealSense | RGB + depth (+ IMU on the D435i) | — | `realsense2_camera` |

### Both microcontrollers hang off a powered USB hub, not the Jetson directly

This is a wiring decision that reads like a downgrade and is not. Plugged straight into
the Orin Nano's own ports, the UNO and the OpenRB-150 both dropped their ttys
intermittently under load — the enumeration would come back on a different device node,
or the port would go quiet mid-match and take the bridge with it — the class of failure
that cost us Final 1 ([`docs/07-results-and-lessons.md` §3.2](../../docs/07-results-and-lessons.md))
and that §8.4 catalogues at the software layer. Moving both boards behind a self-powered USB hub, with only
the two RealSense units and the LiDAR left on the Jetson's ports, was measurably more
stable across the field sessions that followed. Two plausible reasons, neither of which we
instrumented well enough to call proven: the hub supplies bus power from its own rail
instead of the Jetson's, and it isolates the two low-speed CDC devices from the USB3
bandwidth the cameras are saturating.

The practical consequence is that the `by-path` fallback names in `real.yaml` are hub-port
paths — the `usb-0:2.3.1` / `usb-0:2.3.3` pair is two sockets of the same hub. Rearranging
which board sits in which socket renames both ttys, which is why `by-id` is tried first;
see [`docs/06-troubleshooting.md`](../../docs/06-troubleshooting.md) on device-path drift.

### Boot the Jetson with the 12 V kill switch OFF

The other half of the same reliability story, and the one that cost us more time. **The 12 V
rail must be dead while the Jetson boots and enumerates USB.** Switch the rail on afterwards,
once `lsusb` has shown the OpenRB-150. Booted the other way round, that board either never
appears or appears and then drops out under load, taking `gripper_bridge_node` with it — which
is the failure mode the whole of [`gripper-and-mast.md` §5](gripper-and-mast.md#5-one-process-owns-the-tty)
and §8.4 here are downstream of.

We never instrumented it, so the mechanism is a hypothesis and is written here as one: with
12 V live at boot, the OpenRB appears to backfeed into the shared ground / USB path, and the
Jetson's port protection cuts the port rather than enumerating a device it reads as faulty.
That fits the evidence — it is the only board sitting on both the 12 V rail and a Jetson-side
USB path, and boot-time state is what decides the outcome — but it is not measured. The rule
is in the field runbook as step 0
([`docs/05-field-runbook.md` §1](../../docs/05-field-runbook.md#1-power-on-order)); the symptom
table is [`docs/06-troubleshooting.md` §2](../../docs/06-troubleshooting.md#the-openrb-is-missing-or-drops-out-after-booting-with-12-v-live).

Note the asymmetry this creates: the kill switch must be **off** at Jetson boot for the board
to enumerate, and **on** for the Dynamixel bus to have power at all. Off for boot, on before
bringup.

Body frame convention, identical in firmware, `mecanum_control.py` and the URDF generator:
**+x forward, +y left, +yaw counter-clockwise**. Wheel order is always
`(front_left, front_right, rear_left, rear_right)`.

---

## 3. Arduino UNO pin map

The firmware's own `pins` command is the authority; this table is its output
(`mecanum_encoder_control.ino:617-628`).

| Wheel | Driver channel | DIR | PWM | Encoder A | Encoder B |
|---|---|---:|---:|---:|---:|
| front_left (FL) | MDD10A #1 M1 | D4 | D5 | D8 | D9 |
| front_right (FR) | MDD10A #1 M2 | D7 | D6 | A0 | A1 |
| rear_left (RL) | MDD10A #2 M1 | D2 | D3 | A2 | A3 |
| rear_right (RR) | MDD10A #2 M2 | D12 | D10 | **D11** (see §4) | A5 |

| Pin | Use |
|---|---|
| D0, D1 | USB serial to the Jetson — connect nothing |
| D13 | Spare, but it drives the on-board LED; not recommended for an encoder input |
| A4 | Reported dead (stuck low) on 2026-07-14 and masked out of the pin-change interrupt |

All four PWM pins are hardware PWM (Timer0: D5/D6, Timer2: D3, Timer1: D10). Encoders are
decoded with pin-change interrupts and a quadrature state table
(`mecanum_encoder_control.ino:226-278`), so no external-interrupt pins are needed — which is
why D2 and D3 are free for the rear-left motor.

---

## 4. The rear-right encoder A pin

**Sources in the repository disagree about this one pin. Verify it against your own board.**

| Source | Says |
|---|---|
| `mecanum_encoder_control.ino:18` (file header comment) | `Rear-right encoder: A = A4, B = A5` |
| `mecanum_encoder_control.ino:116` (the constant that actually compiles) | `const uint8_t ENC_RR_A = 11;  // PB3 (was A4 — dead line)` |
| `mecanum_encoder_control.ino:622` (`pins` output) | `encA=D11 encB=A5`, `dead=A4` |
| `mecanum_encoder_control.ino:985` (interrupt mask) | `PCMSK1 = ... // A0-A3, A5 (A4 dead — masked out)` |
| Original wiring guide (`docs/hardware/mecanum_wiring.md`, Korean) | RR encoder A = D11; A4 marked *do not use* |
| `ros2/robot_bringup/config/real.yaml` comment | "RR judged after the A4 broken line was **repaired**" |

The code and the wiring guide agree on **D11**; the file-header comment still says A4, and
the `real.yaml` comment implies the A4 line was repaired at some point. **Trust the `pins`
output on your own board**, and treat the header comment as stale.

Related, and equally load-bearing: the rear-right encoder module has a **dead A output**, so
the firmware ships with single-channel counting enabled by default
(`mecanum_encoder_control.ino:186-192`):

```c
volatile bool rrSingleChannel = true;   // default ON until the encoder is replaced
volatile int8_t rrFbRawDir = 2;
```

In this mode every rear-right B edge adds ±2 ticks (so the effective CPR stays 1320), with
the sign taken from the last commanded PWM direction. It loses accuracy only around
direction reversals, and it is part of why the position tolerance had to be relaxed
(§7.3). Turn it off with `rr1ch 0` once the encoder is replaced. This command exists in the
parser (`:890-899`) but is missing from the firmware's own help text — an undocumented
command in the shipped build.

---

## 5. Motor driver wiring (Cytron MDD10A × 2)

Each MDD10A carries two channels; each channel takes **PWM (speed) + DIR (direction)**,
sign-magnitude, with no EN/STBY pin. 10 A continuous / 30 A peak per channel, 5–30 V motor
supply, 3.3 V/5 V-tolerant logic.

| MDD10A terminal | Connect to |
|---|---|
| VM+ / VM− | Battery +12 V / GND (both boards branched in parallel) |
| M1A / M1B | Motor 1 (FL or RL) |
| M2A / M2B | Motor 2 (FR or RR) |
| PWM1 / DIR1, PWM2 / DIR2 | Arduino pins per §3 |
| GND (signal) | **Common with the Arduino GND** |

Notes carried over from the original wiring guide:

- Motor lead polarity (`M?A` / `M?B` swapped) only reverses that wheel. Do not rewire —
  fix it in software with the `sign` command (§6.2).
- MDD10A accepts PWM up to 20 kHz, so the UNO's default 490/980 Hz is fine.
- The on-board M1A/M1B/M2A/M2B test buttons let you verify power and motor wiring
  **before** the Arduino is connected. Do this first.
- **Common ground is mandatory**: battery GND ↔ both MDD10A GND ↔ Arduino GND ↔ Jetson
  (via USB). A missing common ground was the suspected cause of a 2026-06-26 motor fault.
- Never power motors from the Arduino 5 V rail.

The firmware also supports the older inverted-PWM driver style (forward = DIR HIGH,
`analogWrite(255 - duty)`) as a runtime switch, because the project ran on such a board
while waiting for the MDD10A units:

```
mstyle 1 1 1 1      # MDD10A sign-magnitude (the shipped default)
mstyle 0 1 0 1      # the legacy diff-drive driver's mixed left/right convention
```

Using style 0 with an MDD10A makes reverse duty the complement of the command — full
reverse produces duty 0. That bug is documented in-line at
`mecanum_encoder_control.ino:324-334`.

---

## 6. Encoder wiring and polarity

- Each encoder: A, B, VCC, GND. **VCC comes from the Arduino 5 V rail**, not from motor power.
- A0–A5 are used as digital inputs with internal pull-ups, so open-collector encoder
  outputs work unmodified.
- Swapping A and B only inverts the count sign — fix it in software.

### 6.1 Counts per revolution

`ENCODER_CPR = 1320` (`mecanum_encoder_control.ino:120-122`): JGB37-520, 11 PPR hall × 4×
quadrature decode × 1:30 gearbox. Bench-confirmed on 2026-07-14 from the no-load full-PWM
tick rate (~1330 measured). Re-measure with `bringup_tools/20_encoder_cpr_calib.py` if you
use a different gearmotor.

### 6.2 Polarity, fixed in software

Bench calibration on 2026-07-14 found that all four motors were wired so that positive PWM
drives the wheel backwards, and that the FR and RR encoders had A/B swapped. Rather than
rewire, the polarity lives in two arrays that both the firmware defaults and
`real.yaml` carry:

```
motor_signs:   [-1, -1, -1, -1]
encoder_signs: [ 1, -1,  1, -1]
```

`10_wheel_selftest.py` determines these for you and prints both the firmware `sign` line and
the YAML snippet.

---

## 7. The control cascade

Everything below runs **on the Arduino**, not on the Jetson.

### 7.1 Inner loop — per-wheel velocity PID at 50 Hz

`PID_INTERVAL_MS = 20`. Wheel speed is reconstructed from tick deltas, then
(`mecanum_encoder_control.ino:477-499`):

```
feedforward = min_pwm + ff_slope * |target|
output      = feedforward * sign(target)
            + kp * error + ki * ∫error dt + kd * d(error)/dt
output      = clamp(output, -max_pwm, +max_pwm)
```

The integral is clamped to `±integral_limit`, and targets below 0.01 rad/s reset the loop
and command zero (so a stopped wheel does not wind up).

Shipped gains and where they came from:

| Parameter | Value | Provenance |
|---|---:|---|
| `speed_kp` | 10.0 | 2026-07-14 block step tuning on JGB37-520, re-tuned 2026-07-15 under floor load |
| `speed_ki` | 8.0 | No-load gains (`ki=5`) let the front-left wheel sag −18 % at low speed on the floor |
| `speed_kd` | 0.0 | Not needed |
| `min_pwm` | 10.0 | Feedforward offset to break stiction |
| `max_pwm` | 250.0 | — |
| `feedforward_slope` | 6.9 | Fitted from an open-loop PWM/speed sweep |
| `integral_limit` | 20.0 | Raised with `ki` for the same floor-load reason |

Acceptance after re-tuning: steady-state error < ±6 % at 3, 6 and 9 rad/s forward and
reverse, rise time from standstill < 0.6 s — with the rear-right wheel in single-channel
mode.

### 7.2 Outer loop — position, with a synchronized trapezoid

A `d` (or `pw`) command starts a position move (`:401-449`, `:517-609`):

1. Convert the body displacement to four wheel-angle deltas with the same inverse
   kinematics used for velocity.
2. Build a trapezoidal profile for the **longest-travel wheel** using `position_max_rad_s`
   and `position_accel_rad_s2` (collapsing to a triangle if the move is short), then scale
   the other three wheels proportionally — so all four start and finish together.
3. Every 20 ms, sample the profile, and command
   `velocity_target = profile_velocity + posKp·position_error + posKd·d(error)/dt`
   into the inner loop.
4. After the profile ends, if any wheel is still outside `position_tolerance_rad`, floor its
   correction speed at `position_min_rad_s` so stiction cannot park it just under the PWM
   dead band. Once all four wheels are inside tolerance for `position_hold_ms`, the move is
   done.

Two guards worth stealing:

- **Runaway clamp.** The corrective term is clamped to `1.15 × position_max_rad_s`, not to
  the global wheel limit. Comment at `:585-590`: after `MAX_WHEEL_RAD_S` was raised 16 → 30,
  an unbounded `posKp` correction actually did exceed the caller's `max_v`, producing a
  terminal deceleration spike, wheel slip and objects being knocked over.
- **Deadline, not a fixed timeout.** `deadline = 2 × profile_time + 5 s` (`:446-448`).
  Raised from +1.5 s → +2.5 s → +5.0 s: on 2026-07-19 a 0.3–0.4 m approach hop timed out in
  the arena, the caller proceeded anyway, and the gripper closed on empty air.

### 7.3 Position tolerance: the number we relaxed three times

| Date | `position_tolerance_rad` | Wheel-surface error | Why |
|---|---:|---:|---|
| initial | 0.035 | ≈ 1.2 mm | Bench value |
| 2026-07-15 | 0.08 | ≈ 3 mm | Floor load + rear-right single-channel settling noise made strafes and turns fail to hold → timeouts |
| 2026-07-16 | 0.20 | ≈ 7.8 mm (≈ 2.2° of yaw) | Small moves and turns chattered outside 0.08 on stiction; 3 of 8 turns in an arena end-to-end run hit the 4.9 s timeout |
| 2026-07-20 | **0.30** (+ `position_hold_ms` 100 → 50) | ≈ 11.7 mm | Under carry load (reversing with an object, approaching and backing off the storage box) half of all single moves burned the deadline, costing 36–74 s per run. Storage still succeeded 5/5, so effective precision was unchanged — only waiting time was recovered |

The honest reading: this is not a precise base. It is a base whose imprecision (≈ 12 mm) is
comfortably inside the grasp lateral tolerance (±55 mm), and we spent the difference on
time.

### 7.4 Kinematics

X-configuration mecanum, identical in `mecanum_encoder_control.ino:358-364` and
`ros2/robot_hardware/robot_hardware/mecanum_control.py:69-79`:

```
FL = (vx − vy − k·wz) / r        k = half_length + half_width
FR = (vx + vy + k·wz) / r        r = wheel_radius
RL = (vx + vy − k·wz) / r
RR = (vx − vy + k·wz) / r
```

`r` and `k` are **fitted** values (0.0388 m and 0.198 m), not ruler measurements — see
[`../README.md`](../README.md#34-understand-which-constants-are-effective-not-physical).

Speed ceilings: firmware `MAX_WHEEL_RAD_S = 30.0` rad/s (raised from 16 on 2026-07-17 —
16 rad/s was 0.62 m/s, an artificial cap far below the motor's 34.9 rad/s no-load speed);
the effective limit is the bridge's `max_wheel_rad_s: 26.0`, with body caps
`max_linear_x_mps: 0.9`, `max_linear_y_mps: 0.6`, `max_angular_rps: 2.0`.

---

## 8. Arduino serial protocol (115200 8N1, one command per line)

### 8.1 Commands

| Command | Meaning |
|---|---|
| `m <vx_mps> <vy_mps> <wz_rad_s>` | Body velocity (velocity mode). Replies `OK m` |
| `w <fl> <fr> <rl> <rr>` | Per-wheel angular velocity targets, rad/s. Replies `OK w` |
| `d <dx_m> <dy_m> <dyaw_rad>` | **Relative body displacement** (position mode). Replies `OK move`, then `DONE,move,...` or `ERR move timeout` |
| `pw <fl> <fr> <rl> <rr>` | Relative wheel position deltas in rad (position mode) |
| `p <fl> <fr> <rl> <rr>` | Direct signed PWM, −255..255; disables the closed loop until the next `m`/`w`/`d` |
| `pid <kp> <ki> <kd> <min_pwm> <max_pwm> <ff_slope> <int_limit>` | Velocity loop tuning (shared by all wheels) |
| `ppid <kp> <kd> <max_rad_s> <accel> <tol_rad> <hold_ms> <min_rad_s>` | Position loop tuning |
| `geom <wheel_radius_m> <half_length_m> <half_width_m>` | Kinematics geometry used by `m` and `d` |
| `sign <m_fl> <m_fr> <m_rl> <m_rr> <e_fl> <e_fr> <e_rl> <e_rr>` | Per-wheel motor and encoder polarity (±1) |
| `mstyle <fl> <fr> <rl> <rr>` | PWM encoding style per wheel (0 = DIR_HIGH_PWM_LOW, 1 = PWM_HIGH_DIR_LOW) |
| `rr1ch <0\|1>` | Rear-right single-channel encoder mode (**undocumented in the firmware's own help**) |
| `z` | Zero the encoder counters |
| `stop` | Stop all motors, abort any position move |
| `stream <0\|1>` | Enable/disable periodic `STATE` lines |
| `pins` | Print the pin map and current `mstyle` |
| `test [pwm] [ms]` | Drive each wheel forward then reverse in turn, printing `STEP_TICKS` |
| `?` | Help (also printed at boot, preceded by the `READY` banner) |

### 8.2 Telemetry

```
STATE,<ms>,<fl_ticks>,<fr_ticks>,<rl_ticks>,<rr_ticks>,<fl_pwm>,<fr_pwm>,<rl_pwm>,<rr_pwm>,<mode>
```

at 10 Hz when streaming (`REPORT_INTERVAL_MS = 100`), where `mode` is 0 = idle/PWM,
1 = velocity, 2 = position. Tick values already have `encoder_signs` applied, so they are
positive for physical forward rotation on every wheel.

Other lines: `READY mecanum_encoder_control` (boot banner), `OK ...`, `ERR ...`,
`WARN velocity timeout`, `DONE,move,<fl_err>,<fr_err>,<rl_err>,<rr_err>` (residual error per
wheel, rad), `STEP,...` / `STEP_TICKS,...` during `test`, `PINS ...` / `MSTYLE ...`.

Safety: velocity mode auto-stops if no new command arrives within
`VELOCITY_TIMEOUT_MS = 500` and prints `WARN velocity timeout`. Position mode is bounded by
its deadline (§7.2).

### 8.3 The ROS contract on top of it

`mecanum_bridge_node` (`ros2/robot_hardware/robot_hardware/mecanum_bridge_node.py`):

| ROS | Direction | Serial |
|---|---|---|
| `/cmd_vel_motor` (`geometry_msgs/Twist`) | in | `m <vx> <vy> <wz>` at up to 20 Hz, resent at least every 0.2 s |
| `/base/move_relative` (`std_msgs/String`, JSON `{dx, dy, dyaw, max_v?}`) | in | `d <dx> <dy> <dyaw>`, preceded by a fresh `ppid` if `max_v` changes this move's cruise cap |
| `/base/move_result` (JSON `{ok, reason, wheel_errors_rad, elapsed_sec}`) | out | from `DONE,move,...` / `ERR move timeout` |
| `/safety/e_stop` (`Bool`) | in | `stop` |
| `/chassis/odom`, `/joint_states`, `/motor/state` | out | from the `STATE` stream |

This is what makes a Nav2-free mission possible: the planner asks for "20 cm forward" or
"45° left" and gets a completion event with per-wheel residuals, instead of running its own
controller.

Note that the primitive is genuinely holonomic: `d 0.30 0.20 -0.79` is one move in which the
robot translates **and** yaws simultaneously, because all three components go through the
same inverse kinematics and produce one synchronized trapezoid. A caller that wants a
mecanum "drift" — slewing to a heading while driving — sends it as one goal rather than as a
rotate followed by a strafe.

### 8.4 Five serial-layer bugs, and their fixes

These cost real field time and are the most transferable part of this document.

1. **The UNO's 64-byte RX buffer overflows right after boot.** Immediately after `READY` the
   sketch spends tens of milliseconds printing ~500 characters of help text, during which
   `loop()` never drains RX. Blasting the six-command configuration burst truncated the
   `pid` line and lost `stream 1` — so odometry silently stopped. Fix: 300 ms settle plus
   60 ms between lines (`mecanum_bridge_node.py:310-317`).
2. **Non-blocking `readline()` returns half lines.** With `timeout=0`, pySerial happily
   returns a fragment. Fragmented `STATE` lines are invisible, but one fragmented
   `DONE,move` left `move_active` latched forever and every later position move was
   rejected. Fix: accumulate raw bytes and dispatch only complete newline-terminated lines
   (`:475-496`).
3. **`termios.error` is not a subclass of `OSError`.** During a USB reconnect race,
   `reset_input_buffer()` raised it and killed the whole node on the field (2026-07-17). It
   is now caught explicitly at every serial call site.
4. **A rebooting Arduino silently loses its tuning.** All firmware configuration lives in
   RAM. The bridge watches for the `READY` banner and re-pushes geometry, both PID sets,
   signs and `stream 1`, and additionally fails any in-flight move with
   `firmware rebooted mid-move` — otherwise `move_active` sticks (`:513-524`).
5. **Two processes opened the same UNO.** On 2026-07-18 a stray differential-drive
   `motor_bridge_node` from an orphaned launch interleaved commands into the firmware
   parser and corrupted it until the USB was replugged. The port is now opened with
   `exclusive=True` (`:240-253`).

---

## 9. OpenRB-150 serial protocol (115200, USB CDC)

Full command set as implemented in `openrb_gripper.ino:802-1002`. Semantics, calibration
values and the grasp-detection logic are in [`gripper-and-mast.md`](gripper-and-mast.md);
this is the wire-level reference.

### 9.1 Gripper commands (Dynamixel ID 0)

| Command | Effect | Reply |
|---|---|---|
| `OPEN` | Move to `FULL_OPEN_DEG` at `OPEN_CURRENT_RAW` | `OK_MOVE_DEG ...` |
| `CLOSE` | Move to `CLOSED_DEG` at `GRIP_CURRENT_RAW` | `OK_MOVE_DEG ...` |
| `SET_DEG <deg>` | Move to an absolute angle, clamped to the safe arc | `OK_MOVE_DEG <deg> TARGET_DEG <ext> RAW <raw> CURRENT_RAW <cur>` |
| `SET_RATIO <0..1>` | Same, as a fraction of the safe arc | as above |
| `GRIP <deg> <current_raw>` | Set the goal current *and* move | as above |
| `SET_CURRENT <raw>` | Set the goal current only (clamped 10..120) | `OK_SET_CURRENT CURRENT_RAW <n>` |
| `STATUS?` | One-shot telemetry line | `STATUS READY <0\|1> POS_RAW .. POS_DEG .. POS_RATIO .. CURRENT_RAW .. VOLTAGE_RAW .. HW_ERROR .. TORQUE .. FAULT .. CURRENT_LIMIT_RAW .. ACTUAL_CURRENT_LIMIT_RAW .. SAFE_ARC_WRAP .. DXL_POWER .. AUTO_TORQUE_OFF_MS 0 ID .. BAUD .. PROTOCOL ..` |
| `STOP` | Torque off | `OK_STOP` / `ERR_STOP` |
| `TORQUE_ON` | Torque on (refused while a fault is latched) | `OK_TORQUE_ON` / `ERR_FAULT_LATCHED` |
| `REBOOT` | Dynamixel reboot + full reconfigure | `OK_REBOOT` / `ERR_REBOOT` |
| `CLEAR_FAULT` | Clear the latched overcurrent / hardware-error fault | `OK_CLEAR_FAULT` |
| `PING` | Ping ID 0, reconfigure if it was not ready | `OK_PING ... MODEL <n>` / `ERR_PING ...` |
| `SCAN [max_id]` | Sweep protocols 1–2 × 5 baud rates × IDs 0..max | `SCAN_FOUND ...`, `SCAN_DONE COUNT <n>` |
| `SET_DXL <id> [baud] [protocol]` | Retarget the gripper servo | `OK_SET_DXL ...` |
| `DXL_POWER_ON` / `DXL_POWER_OFF` / `DXL_POWER_CYCLE` | Servo bus power (no-op unless the board defines `BDPIN_DXL_PWR_EN`); power-off also invalidates the mast home | `OK_DXL_POWER_*` |

Unknown input returns `ERR_UNKNOWN_COMMAND`.

### 9.2 Camera-mast commands (Dynamixel ID 12)

| Command | Effect | Reply |
|---|---|---|
| `LIFT_TO_TOP` | Absolute move to `stroke − top_margin` above home | `OK_LIFT_TO_TOP HOME <h> <present> -> <goal>` |
| `LIFT_TO_MID` | Absolute move to exactly half of the `LIFT_TO_TOP` target (`openrb_gripper.ino:552-555`) | `OK_LIFT_TO_MID ...` |
| `LIFT_TO_BOTTOM` | Absolute return to home | `OK_LIFT_TO_BOTTOM ...` |
| `LIFT_MOVE <ticks>` | Relative move, magnitude capped at `LIFT_MAX_MOVE_TICKS` (40000) | `OK_LIFT_MOVE <present> -> <goal>` / `ERR_LIFT_MOVE_TOO_FAR` |
| `LIFT_SET_HOME` | Re-declare the present position as floor home | `OK_LIFT_SET_HOME <raw>` |
| `LIFT_STOP` | Freeze at the present position | `OK_LIFT_STOP <raw>` |
| `LIFT_TORQUE_OFF` / `LIFT_TORQUE_ON` | Release / re-engage (multi-turn tracking survives torque-off, not power-off) | `OK_LIFT_TORQUE_*` |
| `LIFT_STATUS?` | Telemetry | `LIFT_STATUS READY .. POS_RAW .. CURRENT_RAW .. MOVING .. HW_ERROR .. TORQUE .. HOME_SET .. HOME_RAW .. STROKE ..` |

Also emitted unsolicited: `LIFT_HOME_SET <raw>` the first time the lift initializes in a
Dynamixel power session, and `WATCHDOG_OPEN` whenever the 3 s gripper watchdog fires.

### 9.3 The ROS contract

| ROS topic | Direction | Serial |
|---|---|---|
| `/gripper/command` (`String`: `OPEN`, `CLOSE`, `STOP`, `SET_DEG <deg>`, `LIFT_*`) | in | corresponding command |
| `/lift/command` (`String`: `LIFT_*` only) | in | pass-through |
| `/gripper/state` (JSON) | out | parsed `STATUS` + node-side bookkeeping |
| `/lift/state` (JSON) | out | parsed `LIFT_STATUS` / `LIFT_HOME_SET` |
| `/gripper/grasp` (JSON `{state, pos_gap_deg, current_raw, samples, stamp}`) | out | derived — see [gripper-and-mast.md](gripper-and-mast.md#3-sensorless-grasp-detection) |

---

## 10. Post-assembly verification sequence

Translated from `firmware/arduino_mecanum/README.md`, with the pin table corrected.

1. `pins` — compare the printed map against your wiring.
2. `test 100 800` — wheels must fire in FL → FR → RL → RR order.
   - Wrong order → driver channels are swapped.
   - `STEP_TICKS` = 0 → that encoder is not wired (or its A line is dead).
   - Negative ticks on a forward step → that encoder's A/B are swapped; fix with `sign`.
   - Wheel spins backwards → fix that wheel's motor sign with `sign`.
3. `geom <r> <half_l> <half_w>` with your measured values, then `m 0.1 0 0` — all four
   wheels must rotate forward.
4. `m 0 0.1 0` — the robot must strafe **left** (FL and RR backward, FR and RL forward). If
   it moves diagonally, the mecanum wheels are not in X configuration.
5. `d 0.2 0 0` — 20 cm forward. Measure it with a tape and check the `DONE,move` residuals.

Then continue with the numbered chain in [`../bringup_tools/`](../bringup_tools/) to fit the
effective geometry and the PID gains.

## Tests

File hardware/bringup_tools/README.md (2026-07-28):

# Mecanum bring-up scripts

Run these in numeric order on a freshly built chassis. Each one ends by printing
the values you should write into `hardware/ros2/robot_bringup/config/real.yaml`
or push into the firmware — that is the point of the whole chain: you finish it
holding a calibrated robot, not a pile of notes.

| Step | Command | Preconditions |
|---|---|---|
| 0. Flash firmware | `bash hardware/bringup_tools/00_flash_firmware.sh` | USB connected, ROS bridge **stopped** |
| 1. Wheels / encoders / signs | `python3 hardware/bringup_tools/10_wheel_selftest.py` | Robot **on blocks**, bridge stopped |
| 2. Measure encoder CPR | `python3 hardware/bringup_tools/20_encoder_cpr_calib.py` | On blocks, bridge stopped |
| 3. Tune wheel PID | `python3 hardware/bringup_tools/30_pid_step_tune.py` | On blocks, bridge stopped |
| 3b. Verify PID on the floor | `python3 hardware/bringup_tools/31_pid_floor_verify.py` | On the floor, bridge stopped |
| 4. Determine LiDAR orientation | `python3 hardware/bringup_tools/40_lidar_orientation_check.py` | LiDAR driver **running** |
| 5. Motion accuracy (odometry) | `python3 hardware/bringup_tools/50_move_accuracy.py` | On the floor, ROS bridge **running** |
| 5b. Motion accuracy (LiDAR-referenced) | `python3 hardware/bringup_tools/51_move_accuracy_lidar.py` | On the floor, bridge running |
| 5c. Single-wall pose check | `python3 hardware/bringup_tools/52_single_wall_verify.py` | Facing a flat wall, bridge running |
| 5d. Maximum speed | `python3 hardware/bringup_tools/53_max_speed.py` | Clear floor, bridge running |

## The one thing that trips people up

**Steps 0–3 talk to the firmware over the serial port directly, so
`mecanum_bridge_node` must NOT be running** — two processes cannot own the same
tty. Steps 4 onward are the opposite: they need the ROS bridge up.

If a script hangs waiting for a serial reply, this is almost always why.

## Notes

- Steps 1–3 want the robot **on blocks** with the wheels free. Step 1 reverses
  each wheel individually; on the floor it will simply drive away.
- Step 1 is where you fix polarity. The firmware's `sign` command flips motor
  and encoder direction per wheel without reflashing, so correct it there rather
  than rewiring.
- Step 3b exists because PID gains tuned with unloaded wheels are optimistic.
  Verify them under real floor friction before trusting them.
- Step 4 matters more than it looks: a LiDAR mounted 180° out produces a map
  that is entirely self-consistent and completely wrong.

See `hardware/docs/wiring-and-firmware.md` for the pin map and the full serial
protocol, and `docs/05-field-runbook.md` for the competition-day procedure.

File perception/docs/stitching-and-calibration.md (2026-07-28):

# Stitching and Calibration

Two RealSense cameras, one virtual frame. This document is the reference for the two
calibrations that make that frame usable: the **geometric** stitch (`near → top`, one 3×3
matrix per mast height, venue-independent) and the **photometric** lock (exposure / gain /
white balance, venue-dependent and re-measured on site).

The runtime contract the stitch has to satisfy — inference on the stitched frame, 3D
back-projection always in the *source* camera — is described in
[`pipeline.md` §1](pipeline.md#1-capture-and-stitch) and §7 and is not repeated here.
The operator procedures are in
[`../../docs/04-getting-started.md` §10.3–10.4](../../docs/04-getting-started.md#103-stitch-calibration--must-be-re-measured-on-your-robot),
and the symptom-first version is in
[`../../docs/06-troubleshooting.md` §4](../../docs/06-troubleshooting.md#4-cameras-stitch-seam-and-photometry).
This page is the *why* and the *format*.

**Contents**

1. [Why two cameras](#1-why-two-cameras)
2. [What the calibration is, and what it is per](#2-what-the-calibration-is-and-what-it-is-per)
3. [The `mid` height, and why it is not here](#3-the-mid-height-and-why-it-is-not-here)
4. [File format](#4-file-format)
5. [How the calibrator fits `A`](#5-how-the-calibrator-fits-a)
6. [The measured FHD result](#6-the-measured-fhd-result)
7. [Why one point was not enough](#7-why-one-point-was-not-enough)
8. [Resolution independence](#8-resolution-independence)
9. [Photometry: why it is locked](#9-photometry-why-it-is-locked)
10. [When to re-calibrate](#10-when-to-re-calibrate)

---

## 1. Why two cameras

A D435 colour stream has a vertical field of view of about 42°. The robot has to see, in the
same 3-minute match, a cube 3.5 m away at the far wall *and* a cube 25 cm in front of the
gripper. One 42° camera cannot do both: aim it at the horizon and the floor immediately in
front of the robot falls out of the bottom of the frame; aim it down and the far half of the
arena disappears.

So the robot carries two, on the same lifting mast, at fixed and very different tilts:
a **top** camera at ~19° below horizontal for search, and a **near** camera at ~53° for the
final approach and grasp alignment. The mount table is in
[`pipeline.md` §7](pipeline.md#7-depth-back-projection-to-a-3d-target).

Projecting those mounts onto the floor (mount pose from `perception/fieldlib.py:41`–`52`,
intrinsics from the crop model at 1920×1080, `perception/fieldlib.py:235`) gives the coverage
each camera actually has. These are derived numbers, not tape-measure ones:

| Mast | Camera | Vertical rays (below horizontal) | Floor coverage ahead of the wheel axis |
|---|---|---|---|
| down | top | −2.97° … 39.85° | 0.62 m → far wall |
| down | near | 31.56° … 74.84° | 0.27 m … 0.70 m |
| up | top | −2.02° … 40.80° | 0.78 m → far wall |
| up | near | 31.60° … 74.88° | 0.31 m … 0.94 m |

Two things follow.

- **The top camera alone is blind inside 0.78 m** with the mast up — which is exactly the
  band the gripper works in. The near camera exists to cover it.
- The two coverages **overlap** by about 15 cm of floor (0.78–0.94 m, mast up). That strip is
  the only place a single 2D transform can join the two images, and it is where every
  correspondence point has to be picked. The field runbook independently quotes the same
  strip as "77.5–92 cm ahead of the robot, ±40 cm laterally", which is where the tuner's
  floor-brightness statistics are measured.

The stitch seam is placed inside that strip: `seam = 1044` of a 2044-row stitched frame
corresponds to floor distance **0.82 m** ahead. Everything above row 1044 is top-camera
pixels, everything below is warped near-camera pixels.

One consequence is worth stating plainly because no calibration can fix it: **the alignment
is exact on the floor plane only.** The two cameras are ~4 cm apart vertically and tilted
34° apart, so anything with height that straddles the seam has parallax and will ghost. That
is why the calibration target must be flat, and why the seam is placed at 0.82 m rather than
somewhere an 8 cm cube is likely to sit during a scan.

Both cameras ride the mast (a 2026-07-18 conclusion that the lower one was chassis-mounted
was a mis-labelled measurement — see
[`../../hardware/docs/gripper-and-mast.md` §4.4](../../hardware/docs/gripper-and-mast.md#44-mast-height-is-a-perception-parameter)),
so the relative pose of the two cameras — and therefore the stitch — changes with mast height.

---

## 2. What the calibration is, and what it is per

The stored model is a single 3×3 homography `A` mapping **near pixels into the top frame
extended downward** (`perception/fieldlib.py:252`). `seam`, `left`, `right` and `out_h` say
how the composite frame is cut from it, and `to_source()` (`perception/fieldlib.py:375`) is
its exact inverse, which is what keeps depth back-projection valid.

The calibration is **per mast height and per camera pair**, and it is **not** per venue:

| Varies with | Stitch geometry (`up.json` / `down.json`) | Photometry (`arena.json`) |
|---|---|---|
| Mast height | **yes** — separate file per height | yes — measure with the mast **up** |
| Camera brackets touched / camera swapped | **yes** — re-fit | no |
| RGB resolution | no — rescaled analytically (§8) | no |
| Room lighting | no | **yes** — re-measure at every venue |

Both shipped heights are load-bearing at runtime: the 12-shot centre scan uses `up`
(`mission/match_runner.py:1061`), the mast-down pre-shot that owns the four near cells uses
`down` (`mission/match_runner.py:1049`), and the pre-grasp re-verification also uses `down`
(`mission/match_runner.py:1544`).

If a calibration file is missing, `Stitcher` falls back to the legacy translation-only
parameters in `STITCH_PARAMS` (`perception/fieldlib.py:57`) and reproduces the pre-2026-07-19
pipeline **bit for bit** — `tests/test_stitcher_calib.py` asserts exactly that, for both the
stitched pixels and `to_source()`. Deleting a calibration file is therefore a safe rollback
that requires no code change.

---

## 3. The `mid` height, and why it is not here

`perception/fieldlib.py` defines `TOP_MOUNT_MID` / `NEAR_MOUNT_MID` (an interpolation of the
up/down fits, flagged in the source as an estimate), the calibrator accepts `--mast mid`
(`perception/tools/stitch_calibrator.py:1026`), and the match runner accepts
`--scan-mast mid`.

**No `mid.json` is shipped, and `mid` was never used in competition.**

The reason is not policy, it is the file itself: the `mid.json` that once existed was a
**byte-identical copy of `up.json`** — same MD5, same six correspondence points, same
`created` timestamp, and `"mast": "up"` still inside it. No `mid` fit was ever performed.
Shipping it would have published a calibration that silently claims to be something it is not.

The code handles the absence correctly and loudly. `--scan-mast mid` is gated on the file
existing and exits with an explicit error telling you to raise the mast to `LIFT_TO_MID` and
run the calibrator (`mission/match_runner.py:2406`–`2410`). `photometry_tune.py` does not
offer `mid` at all — `--mast` is `("up", "down")` (`perception/tools/photometry_tune.py:418`).
Every competition run used `--scan-mast up`, the default.

---

## 4. File format

`perception/calibration/stitch/{up,down}.json`, written by `save_calib()`
(`perception/tools/stitch_calibrator.py:921`). Every field:

| Field | Meaning |
|---|---|
| `version` | `2` — the `A`-matrix format. Version 1 was the translation-only parameter set. |
| `res` | **The pixel coordinate system this file lives in**, e.g. `[1920, 1080]`. The single source of truth for §8's rescale. Written from the calibrator's own state, deliberately *not* re-read from the frame, so it can never disagree with `A`. |
| `mast` | `up` or `down`. Informational — the filename is what the loader keys on. |
| `model` | Which family was fitted: `translate` / `similarity` / `affine` / `homography`. |
| `A` | 3×3 near→top-frame transform, row-major. The only field the geometry depends on. |
| `seam` | Row in the top frame where top pixels stop and warped near pixels start. |
| `left`, `right` | Horizontal crop of the composite, in top-frame columns. Always recomputed from `A`'s real coverage (`coverage_bounds`, `perception/tools/stitch_calibrator.py:425`), never inherited from an older file — that inheritance is what left the FHD stitch cropped to a 4:3 sub-window before 2026-07-21. |
| `out_h` | Total stitched height = the lowest top-frame row the warped near image reaches. Recomputed if the calibration is rescaled to another resolution. |
| `points` | Every correspondence used, as `{"top": [u,v], "near": [u,v], "src": "manual"｜"auto"}`. Kept so a fit can be audited or re-run offline without the robot. |
| `residual_px.per_point` | Reprojection error of each point under the fitted `A`, in pixels. |
| `residual_px.rms` | RMS over **all** points, including RANSAC outliers. Not the acceptance metric. |
| `residual_px.rms_inlier`, `n_inlier`, `n_outlier`, `inlier_thresh_px` | The acceptance metric and its population: RMS over points within `inlier_thresh_px` (3.0) of the fit. See §5. |
| `decomposition` | Human-readable `scale_x`, `scale_y`, `rot_deg`, `dx`, `dy`, `persp` of `A`. Never read by the runtime — it exists so a human can sanity-check that a fit is a plausible camera-to-camera relationship and not a numerical accident. |
| `created`, `source` | Timestamp and where the frames came from (live topics, or an offline pair directory; `❄ FREEZE` if the live view was latched). |
| `note` | One-line summary auto-generated at save time. |

Saving backs the previous file up to `<mast>.json.bak_<timestamp>` first.

---

## 5. How the calibrator fits `A`

`perception/tools/stitch_calibrator.py` is a small HTTP server (default port 8099) that
serves a browser UI over either live camera topics or a directory of saved `*_top.png` /
`*_near.png` pairs. Working offline from saved pairs is a first-class mode — arena time is
scarce, and the fit does not need the robot.

**1. Correspondence points.** You click a physical point in the top image and then the same
physical point in the near image. A magnifier follows the cursor; a freeze button latches one
live frame so clicking, fitting and analysis all refer to the same pixels. Minimum 4 points,
recommended 6–8, spread across the **full width** of the overlap band. `auto_match()`
(`:284`) can propose candidates by AKAZE-matching the two images inside the band after
CLAHE, but an arena floor is usually too featureless for it to help much, and its output is
tagged `"src": "auto"` so a later reader can tell.

**2. The fit** (`fit_A`, `:168`). Four model families, each with a minimum point count:

| Model | Min points | Degrees of freedom captured |
|---|---:|---|
| `translate` | 1 | dx, dy |
| `similarity` | 2 | + uniform scale, roll |
| `affine` | 3 | + anisotropic scale, shear |
| `homography` | 4 | + perspective |

With ≥6 points the fit is RANSAC (`estimateAffinePartial2D` / `estimateAffine2D` /
`findHomography`, reprojection threshold 3.0 px); below that it falls back to a closed form —
a complex-number least squares for `similarity` (`y = c·x + t`, where `c` carries scale and
rotation together) and `np.linalg.lstsq` for `affine` — so the tool stays usable with four
points.

**3. The conditioning guard.** This is the part that matters most, and it is the result of a
simulation study recorded in the source (`:180`–`:196`). The overlap band is short in the
vertical direction, so correspondence points are inevitably squashed into a narrow range of
`v`. With 1 px of click noise and 8 points, the predicted error at the frame edges is:

| Vertical spread of the points | 5 px | 20 px | 40 px | 60 px |
|---|---:|---:|---:|---:|
| `similarity` | 1.2 | 1.1 | 1.1 | 1.2 |
| `affine` | 1.9 | 1.8 | 1.8 | 1.8 |
| `homography` | **330** | **83** | **46** | 6.0 |

A homography needs vertical spread to observe its perspective terms; without it the fit is
unconstrained and the corners diverge by hundreds of pixels while the residual at the clicked
points still looks fine. `similarity` is immune because the ~1900 px of *horizontal* extent
constrains roll on its own. So `fit_A` **refuses** to fit a homography below 40 px of vertical
spread and an affine below 15 px, and says which model to use instead. This is a hard refusal,
not a warning — a diverging homography is not detectable from the residual you are looking at.

**4. Inliers versus outliers** (`quality`, `:257`). RANSAC discards points at >3 px, but the
headline RMS is computed over *all* points, so a couple of mis-clicks drag it up and make a
good fit look bad. The docstring records the case that motivated the split: a `down`
calibration read 3.70 px overall and 0.93 px over its 4 inliers. **The acceptance threshold of
≤ 1.5 px is judged on the inlier RMS.** The UI colours the number green below 1.5 px, reports
`n_outlier` separately, and tells you what an outlier usually means: a mis-click, or a point
on an object with height rather than on the floor.

**5. Edge check** (`edge_check`, `:319`). Independently of the point fit, the band is split
into left / centre / right thirds and each third is phase-correlated between the top image and
the warped near image. Three *different* residual shifts mean scale or roll error is left over
— the thing a translation can never fix. Acceptance is all three within ±2 px (the
`--report` mode judges ≤3 px and sets the exit code). This is the metric that diagnosed the
original problem (§7), and it is the one to trust, because it uses every pixel in the band
rather than the handful you clicked.

---

## 6. The measured FHD result

Both shipped files were fitted natively at 1920×1080 on 2026-07-21, from live topics.

| | `up.json` | `down.json` |
|---|---|---|
| Model | affine, 6 points | similarity, 12 points |
| **Inlier RMS** | **0.78 px** (6 of 6 inliers) | **1.13 px** (5 of 12 inliers) |
| RMS over all points | 0.78 px | 5.39 px |
| Worst point | 1.26 px | 11.94 px |
| `scale_x` / `scale_y` | 1.00852 / 0.99212 | 1.02307 / 1.02307 |
| Rotation | 0.479° | 0.996° |
| `dx` / `dy` | −19.26 / +956.71 px | −32.20 / +998.35 px |
| `seam` / `out_h` | 1044 / 2044 | 1044 / 2137 |
| `left` / `right` | 0 / 1908 | 0 / 1912 |

Notes an implementer should not skip:

- **`up` is the good one.** 0.78 px inlier RMS with zero outliers, worst point 1.26 px, and
  the `left`/`right` bounds recovered to the full real coverage (0–1908 of 1920) rather than
  the inherited 4:3 crop.
- **`down` passes on inliers and is honestly weak overall.** 7 of its 12 points were rejected
  at the 3 px threshold, two of them at ~10–12 px. Read the point list and the reason is
  visible: several entries are near-duplicate clicks on the same marker across frames. Per §5
  the correct response is to delete the high-residual points and re-fit. `down` is used only
  for the mast-down pre-shot and the pre-grasp re-check, both at short range, which is why it
  survived as fitted. If you re-fit anything, re-fit this one.
- **Why `affine` for `up` and not `homography`.** The six `up` points span 33.7…60.7 px in
  near-image `v` — a spread of **27 px**. That clears the affine guard (≥15 px) and is
  rejected by the homography guard (≥40 px), exactly as designed. The `down` points span
  18.0 px, which is why `similarity` was used there.
- The fitted rotation of 0.479° for `up` is an independent confirmation of the roll error that
  phase correlation measured as ≈0.53° before any of this existed (§7). Two different methods,
  same number.
- `scale_x ≠ scale_y` for `up` (1.0085 vs 0.9921) is the anisotropy that motivated affine over
  similarity; it is small but it is 3 px across a 1908 px frame.

---

## 7. Why one point was not enough

Every stitch parameter before 2026-07-20 came from **one** correspondence — the front-face
marker of an 8 cm cube. One point determines translation and nothing else: it constrains
neither the scale difference (the two cameras do not have identical effective fields of view)
nor the relative roll. The result is the classic symptom: the seam matches in the middle and
splays apart at both edges.

Phase correlation over 81 saved pairs put a number on it:

| Mast | Left | Centre | Right |
|---|---|---|---|
| up | dx +13.30 / dy −10.54 px | +11.87 / −11.69 | **+7.74 / −16.42** |
| down | +0.07 / −0.02 | +0.64 / +8.17 | −1.63 / +4.77 |

The 5.6 px of dx and 5.9 px of dy disagreement between the left and right thirds of the `up`
band is ≈0.53° of roll. No amount of nudging `x_offset` removes it.

There was a second error in the same measurement, unrelated to geometry: the original target
was a cube face, i.e. a point **8 cm off the floor**. The two cameras are at different heights,
so an elevated point has parallax and cannot be aligned by any single 2D transform — including
the correct one. Use flat markers on the floor.

`tests/test_stitcher_calib.py::test_calibrator_fit_recovers_known_transform` encodes both
halves of this lesson as an assertion: it synthesises points from a known
similarity transform, checks the fit recovers scale to 1e-4 and rotation to 1e-3, and then
asserts that a **1-point translation fit leaves residuals > 3 px** on those same points.

---

## 8. Resolution independence

A stitch calibration must not be tied to the resolution it happened to be measured at. The
project changed RGB resolution twice (640×480 → 1280×720 → 1920×1080) and re-calibrating on
the arena floor each time was not an acceptable cost.

`Stitcher` therefore rescales the stored `A` analytically
(`perception/fieldlib.py:310`–`329`):

```
A' = S_top · A · S_near⁻¹        where   S = K_new · K_ref⁻¹
```

`S` is a pure affine pixel-to-pixel map, and it is *exact* — not an approximation — because
the two resolutions come from the same lens through a crop-and-scale relationship. `seam`,
`left` and `right` are carried through the top camera's `S`; `out_h` is recomputed from
scratch.

The crop model behind `S` is a measurement, recorded at `perception/fieldlib.py:210`–`217`
and `:235`: the RealSense 4:3 640×480 colour mode is not a downscale of the 16:9 sensor, it
is a **centre 1440×1080 crop scaled by 2.25**. The evidence is the intrinsics themselves —
the near camera measures `fx = 605` at 640 wide, which is a 1440-wide crop of a ~1380 px FHD
focal length (`1380 · 640/1440 ≈ 605`, the reasoning as written in the source comment);
a plain downscale of the full 1920-wide frame would have given `fx ≈ 460` instead.
`crop_model_k()` encodes that, and
`test_crop_model_k_matches_measured_fx_ratio` asserts the 2.25 factor and the 240 px principal
point offset.

Three practical points:

- **Live `camera_info` wins.** The crop model is only the fallback. `make_stitcher()`
  (`mission/match_runner.py:786`) reads real intrinsics from each camera's `camera_info` and
  passes them as `intr`; it drops to the crop model only if a `camera_info` has not arrived
  (`mission/match_runner.py:797`–`802`).
- **Any 16:9 pair works in either direction** (generalised 2026-07-21). An FHD-native
  calibration can be driven at 640×480, a 720p calibration at 1080p, and the 640→FHD path is
  bit-identical to the original implementation. A reference resolution that is neither 640×480
  nor 16:9 is **rejected with an error** rather than silently approximated — see
  `test_rescale_rejects_unknown_ref_res`.
- **The invariant that is actually tested** is not the matrix but the correspondence:
  `test_rescale_preserves_ground_correspondence` asserts `A' · S_near · p == S_top · A · p`
  for sample points at 1280×720 and 1920×1080, and `test_rescale_to_source_exact_inverse`
  asserts `to_source ∘ from_source == identity` after rescaling. The exact-inverse property is
  what the depth back-projection depends on, so it is tested at every resolution.

Because both shipped files are already FHD-native, the robot does no rescaling at all —
`res` is `[1920, 1080]` and the live streams run at 1920×1080×15.

---

## 9. Photometry: why it is locked

### The lock

Auto-exposure and auto white balance are **off** on both cameras, and fixed values are pushed
in at bringup. Two independent reasons:

1. **Two free-running cameras do not converge to the same exposure.** They see different parts
   of the scene at different tilts. Measured 2026-07-20 with the mast up: the seam split by
   **ΔY +12.4**, top brighter. Since the stitched frame is a single image to the detector, a
   split seam means a cube's appearance depends on which side of row 1044 it lands on.
2. **Auto-exposure makes detection non-reproducible.** The face model reads printed fruit
   icons that cover 8–10 % of a cube face (see [`../README.md`](../README.md)); its behaviour
   depends on contrast and colour. With auto-exposure on, the same cube at the same distance
   produces different pixels depending on what else is in frame, so a lab result does not
   transfer to the venue and a venue result is not reproducible five minutes later. Locking
   turns photometry into a *calibration* — one measured number, recorded in a file, re-measured
   when the room changes — instead of a hidden variable.

A related trap, worth repeating because it cost a day: the launch file locked white balance by
passing the **string** `"4600"`, while `realsense2_camera` declares that parameter as a
`double`. The set was rejected and the lock silently never applied. It has to be `"4600.0"`.
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

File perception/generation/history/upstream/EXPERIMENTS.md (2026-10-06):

# 실험 색인

기준일: 2026-07-08

이 문서는 실험 상태를 찾기 위한 기준 색인입니다. 원본 report, generated artifact, historical log는 지우지 않고 각 경로에 보존합니다. README 계열 문서는 이 파일을 기준으로 preferred/fallback/rejected 상태를 요약합니다.

용어: 문서에서 **Cube Detector**는 구 `A1`(full-frame object seg), **Face Classifier**는 구 `cube-face unified`(cube crop 면 분류)를 뜻합니다. 코드/경로/alias(`preferred-a1`, `ABC_model/` 등)는 호환성 때문에 옛 이름을 유지합니다 — 매핑은 [readme.md 용어 정리](./readme.md) 참조. 모델 발전 타임라인도 readme.md에 있습니다.

## Status 용어

| Status | 의미 |
| --- | --- |
| `preferred` | 현재 runtime 또는 training에서 기본 추천값입니다. |
| `current` | 유지보수 중인 현재 구성 요소입니다. 반드시 선택된 checkpoint라는 뜻은 아닙니다. |
| `fallback` | debug, 비교, backup 용도로 유용합니다. |
| `candidate` | 가능성은 있지만 승격되지 않았습니다. validation이 더 필요합니다. |
| `rejected` | production/runtime/training에 직접 쓰면 안 됩니다. 근거 보존용입니다. |
| `deprecated` | 더 나은 구조로 대체되었습니다. |
| `archive` | 과거 기록입니다. |

## 현재 Preferred Runtime

| 실험 | status | runtime 사용 여부 | training 사용 여부 | 핵심 지표 | 판단 | 실패/주의 이유 | report path |
| --- | --- | --- | --- | --- | --- | --- | --- |
| Cube Detector + Face Classifier sparse-icon best | `preferred` | yes | current checkpoint source | mix val all mask mAP50/mAP50-95 `0.967 / 0.894`; box `0.968 / 0.924` (120ep, best epoch 47); **실물 recorded orange 65.1%→95.3%** (목표 80% 초과); arena v3 probe apple/orange 68.8/69.7→81.2/78.8% | 2026-07-08 기본 runtime checkpoint로 Jetson bundle 갱신 (probe30과 동급, 정식 120ep 확정) | blank/sliver 저신뢰 fruit 오탐 17/25 — runtime ambiguity guard(≥0.4) 필수 | [model version](./jetson/ABC_model/cube_face_unified/preferred_v2/MODEL_VERSION.md) |
| Face Classifier readd color-outlier base best | `fallback` | no | sparse-icon run의 init checkpoint | mix val mask mAP50/mAP50-95 `0.970 / 0.894` (best epoch 83); 실물 orange 61.6%→65.1% | 직전 preferred(2026-07-07) — sparse-icon 계보 source로 보존 | 실물 printed-icon 구성 미달이 sparse-icon 사이클의 동기 | [model version](./jetson/ABC_model/cube_face_unified/preferred_v2/MODEL_VERSION.md) |
| A1 + cube-face unified HSV pruned color-outlier best | `fallback` | no | readd run의 init checkpoint | pruned val all mask mAP50/mAP50-95 `0.972 / 0.897`; box `0.972 / 0.925`; orange mask recall `0.890` | 직전 preferred(2026-07-04) — readd line의 source 계보로 보존 | validation은 안정적이나 실물 orange printed-style boundary 미해결이 readd 사이클의 동기였음 | [model version](./jetson/ABC_model/cube_face_unified/preferred_v2/MODEL_VERSION.md) |
| A1 + cube-face unified flat-icon boundary best | `fallback` | no | checkpoint source | expanded val mask mAP50/mAP50-95 `0.974 / 0.901`; box mAP50/mAP50-95 `0.975 / 0.933`; flat icon boundary 개선 실험 | HSV/pruned line의 이전 source 계보로 보존 | 색 outlier pruning 전 계열이며 최신 Jetson bundle은 아님 | [model version history](./jetson/ABC_model/cube_face_unified/preferred_v2/MODEL_VERSION.md) |
| A1 + cube-face unified balanced v2 | `fallback` | no | fine-tune baseline/checkpoint source | v2 mask mAP50-95 `0.87483`; plain recall `0.89644`; apple recall baseline 수준 회복 | flat-icon boundary fine-tune의 계보상 source로 보존 | orange recall은 original baseline보다 낮음 | [balanced v2 summary](./reports/cube_face_unified_eval/balanced_v2_20260629/summary.md) |
| ABC cascade | `fallback` | optional | no | 4-object/about-12-face benchmark에서 약 `20-21 FPS`, `98.26%` face-label match | debugging, geometry comparison, regression check용으로 유지 | unified보다 runtime overhead가 큼 | [optimization log](./jetson/OPTIMIZATION_EXPERIMENTS.md) |

Preferred runtime weights:

```text
preferred-a1:
  jetson/ABC_model/meta_v2_a1_objectseg/a1_yolo26s_seg_meta_v2_50000/weights/best.pt

preferred-unified:
  jetson/ABC_model/cube_face_unified/preferred_v2/weights/best.pt
  runs/segment/cube_face_unified_yolo26n_seg_readd_coloroutlier_base_from_pruned_adamw_lr1e5_ft_v1/weights/best.pt
```

## 모델 실험

| 실험 | status | runtime 사용 여부 | training 사용 여부 | 핵심 지표 | 판단 | 실패/주의 이유 | report path |
| --- | --- | --- | --- | --- | --- | --- | --- |
| 초기 8-class object-only YOLO | `deprecated` | no | no | synthetic object detection은 강해졌지만 face-level identity가 없음 | face-aware Meta V2/ABC/unified 방향으로 대체 | visible fruit/plain face를 결정할 수 없음 | [initial summary](./reports/initial_model_may14_summary.md) |
| Meta V2 dataset | `current` | indirect | yes | object mask, face mask, quad, occlusion metadata 저장 | A1/A2/B/C와 unified export의 기반 | 없음 | [technical reference](./readme_specific.md) |
| A1 object segmentation (Cube Detector) | `current` | yes | yes | val=train box mAP50 `0.9941` / mAP50-95 `0.9784`; **arena held-out(안 본 분포) box mAP50 `0.831` / mask mAP50 `0.821`** | 첫 단계로 유지 (현재 배포) | val=train이라 학습셋 지표는 과대. 실제 일반화는 arena held-out으로 측정 | [Jetson guide](./jetson/README.md) |
| A1 low-LR 추가 fine-tune (`a1_..._50000_lowlr_ft_v1`) | `rejected` | no | 실험 | val=train box mAP50 0.9941→0.9943 (+0.0002, 노이즈); **arena held-out box mAP50 0.831→0.806 (−2.5pp), 4개 지표 모두 하락** | 승격 안 함 — 원본 A1 유지 | near-ceiling 모델에 저LR 추가학습(AdamW lr0=1e-5, 30ep)은 val=train을 미세하게 더 암기하되 안 본 분포 일반화는 오히려 저하(미세 과적합). held-out 평가가 없었으면 놓쳤을 결론 | [A1 held-out 비교](./reports/a1_eval_compare_v1/) |
| A2 visible face segmentation | `fallback` | ABC only | 기본값 아님 | visibility debugging에 유용 | ABC cascade용으로 유지 | multi-stage runtime이 느림 | [Jetson guide](./jetson/README.md) |
| B TinyQuadNet | `fallback` | ABC only | 기본값 아님 | face quadrilateral 복원/보정 | geometry 비교용으로 유지 | 추가 CPU/GPU 작업 필요 | [Jetson guide](./jetson/README.md) |
| C MobileNetV3-Small classifier | `fallback` | ABC only | 기본값 아님 | C orange hard case를 anchor pair exp006에서 회복 | ABC 비교용으로 유지 | warp/classifier stage overhead | [C log](./reports/c_orange_hard_case_experiment_log.md) |
| Cube-face unified v1 | `archive` | no | v2 source checkpoint | 초기 validation에서 synthetic mask mAP50-95 약 `0.897` | lineage baseline | v2보다 plain hard-negative 대응이 약함 | [cube-face eval](./reports/cube_face_unified_eval/summary.md) |
| Cube-face unified balanced v2 | `fallback` | no | source checkpoint | baseline/v1/v2 비교에서 aggregate fitness 최고였음 | flat-icon boundary run의 source 계보로 보존 | orange recall 개선 필요 | [balanced v2 summary](./reports/cube_face_unified_eval/balanced_v2_20260629/summary.md) |
| `verified_fruit_balanced_from_last_adamw_lr5e5_ft_v1` | `fallback` | no | source checkpoint | verified fruit balanced val에서 all mask mAP50-95 `0.896` | flat-icon boundary run의 init checkpoint | 실제 orange icon webcam crop 중 하나가 apple로 흔들림 | [technical reference](./readme_specific.md) |
| `verified_plus_flat_icon_boundary_adamw_lr3e5_ft_v1` best | `fallback` | no | source checkpoint | expanded val all mask mAP50/mAP50-95 `0.974 / 0.901`; flat printed icon boundary line | HSV/pruned line의 이전 source 계보로 보존 | 최신 Jetson bundle은 아님 | [technical reference](./readme_specific.md) |
| `hsv_pruned_coloroutlier_from_last_adamw_lr1e5_ft_v1` best | `fallback` | no | readd run의 init checkpoint | pruned val all mask mAP50/mAP50-95 `0.972 / 0.897`; orange mask recall `0.890`; user orange crop 2장 중 1장만 orange | readd line의 source 계보로 보존 (직전 preferred) | color-outlier pruning이 hue 경계를 좁혀 실물 텍스처 대응이 약해진 것이 readd 사이클의 동기 | [원인 리뷰](./reports/cube_face_unified_eval/hard_set_cause_review_20260705.md) |
| `readd_coloroutlier_base_from_pruned_adamw_lr1e5_ft_v1` best | `fallback` | no | sparse-icon run의 init checkpoint | mix val all mask mAP50/mAP50-95 `0.970 / 0.894` (best epoch 83); 실물 녹화 orange 61.6%→65.1% | sparse-icon 계보 source로 보존 (직전 preferred) | 실물 printed-icon 구성 미달 → sparse-icon booster로 해결 | [원인 분석](./reports/cube_face_unified_eval/why_recorded_set_fails_20260708/analysis.md) |
| `sparse_icon_from_readd_adamw_lr1e5_ft_v1` best (120ep) | `preferred` | yes | current checkpoint source | mix val mask mAP50/mAP50-95 `0.967 / 0.894` (best epoch 47, patience stop @82); **실물 recorded orange 95.3%** (readd 65.1%); arena probe apple/orange 81.2/78.8% | 2026-07-08 Jetson `face-classifier`로 갱신 | blank 저신뢰 fruit 오탐 17/25 — runtime guard 필수 | [model version](./jetson/ABC_model/cube_face_unified/preferred_v2/MODEL_VERSION.md) |

## Runtime FPS 실험

| 실험 | status | runtime 사용 여부 | training 사용 여부 | 지표 | 장치 | 모델 형식 | 입력 source | display | object/face 조건 | 판단 | report path |
| --- | --- | --- | --- | --- | --- | --- | --- | --- | --- | --- | --- |
| Original-ish ABC sequential | `archive` | no | no | 약 `5 FPS` | RTX 5080 dev PC | PyTorch path | 4-object benchmark | off | about 12 faces | 너무 느림 | [optimization log](./jetson/OPTIMIZATION_EXPERIMENTS.md) |
| Batched ABC runtime | `archive` | no | no | 약 `8.7 FPS` | RTX 5080 dev PC | PyTorch path | 4-object benchmark | off | about 12 faces | batching만으로 부족 | [optimization log](./jetson/OPTIMIZATION_EXPERIMENTS.md) |
| ABC `best_stable_5080` | `fallback` | optional | no | 약 `20-21 FPS`, `98.26%` face-label match | RTX 5080 dev PC | optimized mixed path | 4-object/about-12-face benchmark | off | 4 cube-like objects/about 12 visible faces | 최고 안정 ABC fallback | [optimization log](./jetson/OPTIMIZATION_EXPERIMENTS.md) |
| A2 TensorRT/22 FPS ABC attempts | `rejected` | no | no | `22 FPS` 이상 가능했지만 behavior match가 accepted gate 아래로 하락 | RTX 5080 dev PC | TensorRT-heavy ABC variants | 4-object/about-12-face benchmark | off | about 12 faces | behavior 변경 때문에 승격 금지 | [optimization log](./jetson/OPTIMIZATION_EXPERIMENTS.md) |
| A1 TensorRT + unified PyTorch | `candidate` | performance test yes | no | mean `47.45 FPS`, median `52.00 FPS` | RTX 5080 dev PC | A1 `.engine`, face `.pt` | benchmark images | off | mean 4.05 objects / 11.65 faces | unified architecture에 충분한 speed headroom 확인 | [runtime json](./reports/cube_face_unified_eval/unified_runtime_benchmark_a1engine_ptface.json) |
| Webcam fair compare, unified vs ABC | `current` | preview 비교용 yes | no | unified `3.83 FPS`, ABC `1.29 FPS` on captured run reported as `cpu` | dev PC capture run | PyTorch preview path | same 30s webcam capture | preview output generated | sample 8 A1 objects / 5 cube crops / 14 faces | 같은 captured condition에서 unified preview가 더 빠름 | [fair compare summary](./reports/share/fair_30s_compare_20260702_155104/summary.md) |
| Unified fixed-capture stage timing after policy alignment | `current` | preview/regression yes | no | processed `3.83 FPS`; A1 mean `168.7ms`; unified 5-crop batch mean `85.0ms`; per cube `17.0ms` | dev PC CPU capture run | PyTorch `.pt` | same 30s webcam capture | off | 5 cube crops/frame | A1 is the primary CPU bottleneck; runtime crop/resize policy now matches training export | [policy/bottleneck report](./reports/cube_face_unified_eval/unified_runtime_policy_bottleneck_20260703.md) |

## Cube-Face Unified 실험

| 실험 | status | runtime 사용 여부 | training 사용 여부 | 핵심 지표 | 판단 | 실패/주의 이유 | report path |
| --- | --- | --- | --- | --- | --- | --- | --- |
| `cube_face_unified_yolo26n_seg_v1` | `archive` | no | source baseline | A1 crop -> visible face mask/class 구조 가능성 확인 | v2로 대체 | plain hard negative가 충분히 강하지 않음 | [cube-face eval](./reports/cube_face_unified_eval/summary.md) |
| `wholefruit_plainhard_materialized_ft_v1` | `fallback` | no | 기본값 아님 | plain recall 크게 개선 | plain false positive만 최우선일 때 alternate로 보존 | fruit recall/confidence를 과하게 깎음; small apple confidence collapse | [v1 summary](./reports/cube_face_unified_eval/wholefruit_plainhard_20260629/summary.md) |
| `wholefruit_plainhard_balanced_ft_v2` | `fallback` | no | source checkpoint (계보) | mask mAP50-95 `0.87483`; apple mask recall `0.88531`; plain mask recall `0.89644` | 이후 verified/flat-icon/HSV/pruned/readd 계보로 대체됨 | orange recall은 original baseline보다 낮음 | [v2 summary](./reports/cube_face_unified_eval/balanced_v2_20260629/summary.md) |
| `ai_wholefruit_balanced_ft_v1` | `candidate` | no | 기본값 아님 | aggregate improvement는 작고 confidence tradeoff 존재 | 승격 안 함 | real camera validation과 class-specific hard-case check 필요 | [AI summary](./reports/cube_face_unified_eval/ai_wholefruit_balanced_20260630/summary.md) |
| `ai_printed_fullsquare_ft_v1` | `candidate` | no | future low-ratio booster 가능 | printed/full-square style probe confidence 강함 | candidate only | production runtime으로 검증되지 않음 | [technical reference](./readme_specific.md) |

## Readd Color-Outlier Base 사이클 (2026-07-05 ~ 07-08)

fruit-to-fruit 혼동(특히 orange↔apple)의 원인 분석부터 readd fine-tune, 실물 세트 검증까지의 기록 색인.

| 단계 | status | 내용 | 핵심 결과 | report path |
| --- | --- | --- | --- | --- |
| 원인 리뷰 | `archive` | pruning이 hue 경계를 좁힘 + 224 crop에서 껍질 텍스처 소실 진단 | holdout orange 1번이 pruning 전 orange 0.552 → 후 apple 0.521 역전 | [hard_set_cause_review](./reports/cube_face_unified_eval/hard_set_cause_review_20260705.md), [fruit_confusion_search](./reports/cube_face_unified_eval/fruit_confusion_search_20260705.md) |
| readd 추출/게이트 | `current` | pruning 제거분 중 kind=base 13,465장 hardlink 복구, 게이트 5% 기준 | 직전 preferred의 f2f 오류 6.16% → 게이트 PASS | [gate decision](./reports/cube_face_unified_eval/readd_coloroutlier_base_gate_v1/GATE_DECISION.md) |
| readd fine-tune | `preferred` | pruned 51,139 + readd 13,465 mix, AdamW lr0=1e-5, 120ep(patience 35, stop@118, best 83) | mix val mask mAP50/mAP50-95 `0.970 / 0.894` | [model version](./jetson/ABC_model/cube_face_unified/preferred_v2/MODEL_VERSION.md) |
| 잔여 오류 유형 분석 | `archive` | 게이트 val에서 안 고쳐지는 114장 분석 (baseline 오류의 88%) | 잔여 오류 = 그림자/blur/sliver/유사 외형 tail; true-conf 중앙값 0.000 | [persistent 분석](./reports/cube_face_unified_eval/persistent_misclassification_analysis_20260707/analysis.md) |
| 실물 녹화 세트 비교 | `current` | 실물 orange cube 녹화 86 visible-icon 크롭, old vs readd best | orange 인식 61.6% → 65.1% (+4/−1); blank 저신뢰 banana 오탐 6→14 | [recorded 비교](./reports/cube_face_unified_eval/recorded_hardset_old_vs_readd_final_20260708/summary.md) |
| 실패 원인 확정 프로브 | `current` | 아이콘 면적 스윕(합성) + 실패 크롭 확대 재예측 + 학습 분포 비교 | 인식 절벽이 면적 11~20%에 위치, recorded 세트는 8~10%; 확대 시 25/30 정답 전환 → composition gap 확정 | [why 분석](./reports/cube_face_unified_eval/why_recorded_set_fails_20260708/analysis.md) |

## Fruit Texture 실험

| 실험 | status | runtime 사용 여부 | training 사용 여부 | 핵심 지표 | 판단 | 실패/주의 이유 | report path |
| --- | --- | --- | --- | --- | --- | --- | --- |
| production texture policy | `current` | indirect | yes | lab 65%, original filtered 25%, fruitseg30 10% policy | production base 안정 유지 | 없음 | [texture policy](./reports/texture_policy_meta_v2_50000_20260623.md) |
| `ai_wholefruit_balanced` probe | `candidate` | no | low-ratio booster 가능 | top1 `0.950`, strong correct `0.428` | low-confidence signal로 유용하지만 direct production 아님 | banana confidence가 낮은 case 다수 | [candidate probe](./reports/cube_face_unified_eval/fruit_texture_candidate_probe_20260702/report.md) |
| `ai_printed_fullsquare` probe | `candidate` | no | low-ratio booster 가능 | top1 `0.978`, strong correct `0.937` | 가장 깨끗한 booster 후보 | runtime/real-camera validation 필요 | [candidate probe](./reports/cube_face_unified_eval/fruit_texture_candidate_probe_20260702/report.md) |
| `combined_curated` probe | `candidate` | no | cleanup 이후만 가능 | top1 `0.840`, strong correct `0.586` | diversity는 있으나 cleanup 필요 | domain/noise gap | [candidate probe](./reports/cube_face_unified_eval/fruit_texture_candidate_probe_20260702/report.md) |
| web cutout sets | `rejected` | no | no | web_v1/web_v3의 wrong/noisy rate 높음; non-apple -> apple confusion도 주로 여기 집중 | `datasets/fruit_textures/other/web_*` 아래 격리 | slices, packaging, bad masks, wrong objects, noisy backgrounds | [web probe](./reports/cube_face_unified_eval/fruit_texture_web_cutout_probe_20260702/report.md) |

## C Classifier 실험

| 실험 | status | runtime 사용 여부 | training 사용 여부 | 핵심 지표 | 판단 | 실패/주의 이유 | report path |
| --- | --- | --- | --- | --- | --- | --- | --- |
| C orange hard-case anchor pair exp006 | `fallback` | ABC only | 기본값 아님 | orange hard case `0.999999`, apple hard case `0.9972`, original val acc `0.9854` | 최고 C fallback checkpoint | preferred unified runtime에는 포함되지 않음 | [C log](./reports/c_orange_hard_case_experiment_log.md) |
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

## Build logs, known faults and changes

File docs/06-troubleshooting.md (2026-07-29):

# 06 — Troubleshooting

Symptom → likely cause → what to do. Every entry here is something that actually happened to
this robot between 2026-06 and 2026-07-24, on the bench or in the arena. Where a fix is
already in the code, the file and line are cited so you can see the guard rather than trust
this page.

The competition-day short version lives in [`05-field-runbook.md`](05-field-runbook.md); this
page is the long version with the reasoning.

---

## 0. Sixty-second triage

Run this first. It is faster than guessing.

```bash
python3 mission/field_autopilot.py check       # 8 s listen, pass/fail per contract topic
```

Exit `0` = every required stream is present. Exit `2` = something required is missing, and
the failing line names it. Then find the symptom below.

| Symptom | First guess | Action |
|---|---|---|
| Every move command times out, odometry never changes | Battery switch off | Switch on, re-run `check`. Confirm with `field_autopilot.py up --battery-probe` (3 cm probe move) |
| Motors stutter at low speed | Two motor bridges on one tty | `pkill -f mecanum_bridge_node`, relaunch. `field_autopilot.py up` does this automatically |
| No camera topics | RSUSB backend / USB enumeration | `field_autopilot.py down` then `up`. If it persists, physically replug |
| No localisation output | Pose never seeded, or robot not where you told it | Re-place in the start zone facing north, re-run `up` (re-seeds) |
| `LIFT_*` does nothing | OpenRB unpowered or home not captured | Check the kill switch first. Then `check`, then power-cycle the board **with the mast at the bottom** |
| OpenRB absent from `lsusb`, or it vanishes under load | Jetson was booted with the 12 V rail already live | Kill switch off, reboot the Jetson, confirm enumeration, *then* switch the rail on ([§2](#the-openrb-is-missing-or-drops-out-after-booting-with-12-v-live)) |
| Scan finds ghosts or misses cells | Perception, not navigation | Compare against the GT table the runner prints; capture with `field_autopilot.py record` and analyse offline |

---

## 1. Power and motion

### Everything times out and the robot does not move

**Cause.** The battery kill switch is off. The motor bridge still reports "connected" —
the Arduino is powered over USB from the Jetson, so the serial link stays healthy while the
motor rail is dead. That combination is deliberately misleading.

**Action.** `battery_off_signature()` in `perception/fieldlib.py` encodes the test: command a
3 cm move, and if it fails or times out *while wheel odometry stays within 5 mm*, the battery
is off. `field_autopilot.py up --battery-probe` runs it for you.

### The motors stutter, or the firmware stops accepting commands

**Cause.** Two processes are writing to the same Arduino tty. The classic version is an
orphaned diff-drive `motor_bridge_node` left over from a previous launch, sharing the port
with a fresh `mecanum_bridge_node`. Interleaved writes corrupt the firmware's line parser.
On 2026-07-18 this required a physical USB replug to recover.

**Action.** Two guards exist:

- both bridges open the port with `serial.Serial(..., exclusive=True)`
  (`hardware/ros2/robot_hardware/robot_hardware/mecanum_bridge_node.py:252`,
  `motor_bridge_node.py:350`), so the second opener now fails loudly instead of corrupting the
  stream;
- `scripts/run_real_competition_bridge.sh` kills known stale bridge processes before
  launching, and aborts if any survive.

If you launch by hand with `ros2 launch`, you skip the second guard. Check with
`pgrep -af mecanum_bridge_node` before starting.

### A single relative move takes seconds longer than the profile predicts

**Cause.** `move_relative` without an explicit `max_v` runs the firmware's *position* mode,
which is capped by `position_max_rad_s: 6.0`
(`hardware/ros2/robot_bringup/config/real.yaml:91`) — about 0.233 m/s, regardless of the
speed profile. On 2026-07-20 a −0.2 m reverse after a grasp took 8 s where the profile
predicted 1.1 s; the timing matched the firmware's own move deadline
(`profile x2 + 5 s ≈ 7.2 s`), i.e. the move failed to settle and timed out rather than being
slow. Note that a −0.35 m move in the same run took 1.74 s, so distance was not the variable.

**Action.** Pass `max_v` on moves that matter. `match_runner.py` records per-move requested
vs. actual duration in `report.json` (`move_stats`) — check it before blaming the controller.

### Teleop or an external `/cmd_vel` publisher is ignored

**Cause.** `cmd_vel_mux_node` is a strict-priority mux:
`/cmd_vel_direct` > `/cmd_vel` > `/cmd_vel_nav` → `/cmd_vel_motor` at 30 Hz, each source
expiring after 0.4 s. The arena node publishes zeros on `/cmd_vel_direct` even while idle,
which used to mask `/cmd_vel` permanently (2026-07-17).

**Action.** Already fixed: the mux selects the highest-priority **non-zero** source and only
falls back to a zero command if every live source is zero
(`hardware/ros2/robot_bringup/robot_bringup/cmd_vel_mux_node.py:80-104`). If teleop is still
ignored, something is publishing non-zero on `/cmd_vel_direct` — `ros2 topic echo` it.

### Motion stops on its own after half a second

**Cause.** By design. `command_timeout_sec: 0.5` (`real.yaml:74`): the bridge zeroes the
wheels if no new command arrives. A publisher running slower than 2 Hz will produce visible
stutter-stop-stutter.

---

## 2. Serial devices

### The bridge cannot find the Arduino or the OpenRB

**Cause.** `by-id` and `by-path` names are not stable across ports, boards, or hosts. The
`by-path` string encodes the physical USB port on the Orin Nano.

**Action.** `real.yaml` carries a candidate list for exactly this reason — the bridge tries
each in turn (`hardware/ros2/robot_bringup/config/real.yaml:3-4` for the Arduino, `:111-112`
for the OpenRB, ending with a bare `/dev/ttyACM0` / `/dev/ttyACM1` fallback). Add your own
path to the list rather than hard-coding one. Reconnection is retried every
`serial_reconnect_interval_sec: 1.0`.

### The OpenRB is missing, or drops out, after booting with 12 V live

**Symptom.** `lsusb` shows no `ROBOTIS OpenRB-150`, or it shows up and then vanishes once the
robot is doing real work, taking `gripper_bridge_node` down with it. The Arduino, the LiDAR
and both cameras are unaffected. Replugging the OpenRB sometimes helps and sometimes does not.

**Action, and it is an ordering rule, not a fix.** Switch the 12 V kill switch **off**, boot
the Jetson with the rail dead, confirm the board enumerates, and only then switch the rail on
([`05-field-runbook.md` §1](05-field-runbook.md#1-power-on-order)). Booted in that order the
board has been reliable for us; booted with the switch already on it is not.

**Cause — unverified.** We never put a scope on it, so this is a working theory rather than a
diagnosis: with the 12 V rail live at boot, the OpenRB appears to backfeed current into the
shared ground / USB path, and the Jetson's port protection responds by cutting the port
instead of enumerating a device it reads as faulty. That would explain why the failure is
specific to the one board that sits on both the 12 V rail and a Jetson-side USB path, and why
the state at boot decides it. If you reproduce this properly, replace this paragraph with the
measurement. Related and also worth doing: both microcontrollers run behind a powered USB hub
rather than the Jetson's own ports
([`wiring-and-firmware.md` §2](../hardware/docs/wiring-and-firmware.md#2-boards-buses-and-who-owns-what)).

### The robot reboots the Arduino mid-run and then rejects every move

**Cause.** A USB reconnect resets the Arduino. Its RAM-held PID and geometry configuration
returns to firmware defaults, and any in-flight move can never report completion — so
`move_active` sticks and every subsequent move is rejected.

**Action.** Already handled: the bridge watches for the firmware's `READY` banner, fails the
in-flight move explicitly, and re-pushes the configuration
(`mecanum_bridge_node.py:513-524`). If you see `firmware rebooted mid-move` in the log, the
recovery worked — but the cable or the power rail is the real problem.

### Opening the gripper board's tty directly

**Do not.** This is the single most damaging manual action available on this robot.

Opening the OpenRB's serial port from a second process asserts DTR, which **reboots the
board**. Three things happen at once: the gripper force-opens (dropping whatever it holds),
the mast's captured home position — which lives in RAM — is lost, and a subsequent
`LIFT_TO_TOP` then drives toward a position it can no longer bound, into the hard stop.

`gripper_bridge_node` therefore owns the port exclusively (`:219`) and passes `LIFT_*`
commands through to the same board (`:527`), so the mast is driven over `/lift/command` and
never by a second process. This was the fix on 2026-07-19 and it is a hard rule.

```bash
# correct
ros2 topic pub --once /lift/command std_msgs/String "{data: LIFT_TO_TOP}"
# wrong — reboots the board
python3 -c "import serial; serial.Serial('/dev/ttyACM1', 115200)"
```

---

## 3. LiDAR and localisation

### Scans drop out for a few hundred milliseconds and the controller lurches

**Cause.** USB scan dropouts. Downstream consumers see a gap and either stall or act on a
stale pose.

**Action.** `laser_scan_watchdog_node` sits between the driver and everything else: it
subscribes to `/scan_raw`, republishes on `/laser_scan` (plus the `/scan` alias) at a steady
15 Hz, and bridges short gaps by holding the last scan for a bounded time. The relevant knobs
are `raw_fresh_timeout_sec`, `hold_stale_scan_sec`, `restamp_scans` and
`republish_fresh_scan`; the bringup launch sets them explicitly
(`real_competition_bridge.launch.py:199-206`). Note that the launch default and the operator
wrapper disagree on `hold_stale_sec` (`0.0` vs `0.15`) — decide deliberately which you want.

The driver itself is launched with `respawn=True, respawn_delay=2.0`
(`real_competition_bridge.launch.py:250-251`), so a driver crash self-heals in ~2 s.

### The map is mirrored, or obstacles appear behind the robot

**Cause.** LiDAR mount yaw. The launch default is `base_scan_yaw:=3.14159265359` (the sensor's
0° facing the robot's rear, correct for the earlier MK3 mount); the mecanum build ran `0.0`.
A reassembly that rotates the scanner 180° silently inverts the whole world model.

**Action.** `python3 hardware/bringup_tools/40_lidar_orientation_check.py`, then set
`base_scan_yaw` to match. Never guess.

### The pose is 90° off and the robot drives confidently to the wrong wall

**Cause.** The arena is a **square**. Wall-range matching alone has a genuine four-fold yaw
ambiguity, and a bad reseed can settle in the wrong quadrant. In one field run this put the
robot at the wrong start heading and it stored objects in the wrong place.

**Action.** Pass an IMU topic. `arena_control_node` integrates the bottom D435i's gyro-z into
a continuous yaw estimate and uses it as a prior; **once yaw is fixed, the wall-range solution
in a square arena is unique**, and the coarse+refine search becomes a single-yaw global x/y
solve (~200 candidates). Leaving `imu_topic` empty removes the prior and reopens the flip.

```bash
ros2 launch arena_lightweight_control lightweight_real.launch.py imu_topic:=/imu/data ...
```

There is also an online gyro-bias EMA and a 5 s yaw trim while stationary, so a slowly
drifting gyro does not need manual re-zeroing.

### Localisation is slow and the yaw twitches

**Cause.** Full known-map scan matching. Measured at **345–449 ms** per solve on 2026-07-04,
which is long enough for the pose to be stale by the time the controller uses it.

**Action.** Use the default `localization_mode:=wall_range` with a reduced beam count
(`localization_max_beams:=24`). On a synthetic 1080-beam scan the wall localiser measures
**~20.35 ms**. Scan processing is additionally throttled to 10 Hz with QoS depth 1.

### The solver locks onto a far-away pose and x becomes unobservable

**Cause.** A subtle scoring bug worth knowing about even if you write your own localiser.
Beams that return *shorter* than the map predicts were being discarded as "occluded". In a
local window that is harmless; in a global search it lets a distant wrong candidate beat the
true pose because it simply throws away the evidence against it. The synthetic case produced
a 65 cm error.

**Action.** Fixed by *penalising* short returns rather than dropping them
(`penalize_short_returns`). The justification is physical: the scan plane sits at 0.32 m and
the objects are 8 cm tall, so nothing on the arena floor can occlude a wall — a short return
is real evidence, not a missing measurement. Verified at 2 cm / 10 ms on synthetic data.

### The pose snaps back to an old value after the operator resets it

**Cause.** A scan-matching callback that started before the reset finishes afterwards and
overwrites the new pose.

**Action.** Fixed with a `pose_revision` guard (2026-07-04): a result computed against a stale
revision is discarded.

### The robot oscillates near the goal

**Cause.** cm-scale pose jitter combined with a tight yaw tolerance keeps re-triggering the
final-yaw correction.

**Action.** The shipped tolerances are deliberately loose: `xy_tolerance_m: 0.15`,
`yaw_tolerance_rad: 0.40`, with a goal position latch and a wider release tolerance
(`xy_release_tolerance_m: 0.25`, 3 consecutive samples) forming a hysteresis band. Do not
tighten these to "improve accuracy" — measured pose jitter during an in-place rotation is
1.5–2 cm, which is well inside the ±25 cm grid snap that actually matters. Mecanum makes the
final approach gentler because yaw need not change, but it does not remove the jitter.

---

## 4. Cameras: stitch seam and photometry

### The stitched frame lines up in the middle and splays apart at both edges

**Cause.** The calibration was fitted from a **single** correspondence point. One point
determines translation only; it constrains neither scale (field of view) nor roll. Phase
correlation across 81 saved pairs measured the residual as left `dx +13.3 / dy −10.5`, centre
`+11.9 / −11.7`, right `+7.7 / −16.4` — a left↔right disagreement equal to about **0.53° of
roll**.

**Action.** Re-calibrate with several points spread across the **full width** of the overlap
band: `python3 perception/tools/stitch_calibrator.py --mast up`, then open
`http://<robot>:8099/`. Current inlier RMS is 0.78 px (`up`, affine, 6 points) and 1.13 px
(`down`, similarity). Two traps:

- **Use a flat target.** The two cameras are at different heights, so anything raised off the
  floor has parallax that no 2D transform can remove.
- **Do not force a homography.** The overlap band is only ~70 rows tall — not enough vertical
  spread to constrain one. Fitting a homography made the corners diverge by 330 px, while a
  similarity fit stayed at 1.1 px because the full horizontal extent constrains roll on its
  own. `fit_A` now rejects affine/homography when the point spread is insufficient.

### The two halves of the stitch have visibly different brightness or colour

**Cause, part 1 — auto exposure.** If auto-exposure is not locked, the two cameras converge
independently and the seam splits. Measured on 2026-07-20 with the mast up: ΔY **+12.4** at
the seam.

**Cause, part 2 — a type bug.** The launch locked white balance by passing the string
`"4600"`. The `realsense2_camera` parameter is declared as a *double*, so an integer-looking
string was rejected and **the lock silently never applied**. It has to be `"4600.0"`.

**Action.** Lock exposure and white balance explicitly
(`real_competition_bridge.launch.py:171-177`: `camera_auto_exposure:=false`, plus exposure,
gain and a WB value written with a decimal point). Then re-run the venue sweep — see
[`04-getting-started.md` §10.4](04-getting-started.md#104-venue-photometry--must-be-re-measured-at-your-venue).

Do not chase the residual **colour** difference. It is sensor-to-sensor (D435 vs D435i) and
white balance does not touch it: sweeping WB from 3200 K to 6000 K changed ΔR/G by 0.004.

### The seam metrics look terrible and nothing you change helps

**Cause.** You are measuring with the mast **down**. In the down position the overlap band is
29 rows at the extreme edge of both lenses, where vignetting and specular reflection dominate.
Measured 2026-07-20: ΔY **28** with the mast down vs **6** with it up, same lighting.

**Action.** Raise the mast (`LIFT_TO_TOP`) before measuring photometry. The scan — which is
what the stitch is for — happens with the mast up anyway.

### Aligned depth is empty at the left and right edges of the frame

**Cause.** A 4:3 depth profile. The D435's stereo imagers are natively 16:9; asking for
640x480 crops them horizontally and drops the depth H-FOV from ~87° to ~65°, which is
*narrower than the 69° RGB FOV*. Everything near the left and right edge of an FHD colour
frame then has no depth at all, and objects there cannot be located.

**Action.** Keep depth on a 16:9 profile. The shipped default is `848x480x15`
(`real_competition_bridge.launch.py:166`) — full FOV and Intel's recommended resolution. The
reasoning is written out at `real_competition_bridge.launch.py:158-164`.

### RealSense refuses to start the depth stream

**Cause.** A depth profile the sensor cannot produce. The D435 depth stream tops out at
1280x720; asking for 1080p fails negotiation. Aligned depth is resampled to the colour
resolution automatically, so there is no reason to ask.

**Action.** `camera_rgb_profile:=1920x1080x15 camera_depth_profile:=848x480x15`.

### One camera does not enumerate at all on the Jetson

**Cause.** Two D435-class cameras on one Orin Nano under the stock kernel UVC backend.

**Action.** Build the userspace RSUSB backend (`scripts/build_realsense_rsusb.sh`) — the
bottom camera runs on it (`use_rsusb_backend=True`,
`real_competition_bridge.launch.py:235-246`). If it still does not appear, replug; if the
*OpenRB* is the device that vanished, check the kill switch before anything else (that was
the whole cause on 2026-07-21).

---

## 5. Perception

### Face confidence collapsed from ~0.9 to 0.1–0.4 and fruits are mislabelled

**Cause.** The face model is being run at the wrong input size. It was trained at
`imgsz=224`; forcing 640 destroys it.

**Action.** `FACE_IMGSZ = 224` (`perception/fieldlib.py:68`). The most robust fix is to pass
no `imgsz` at all and let Ultralytics use the checkpoint's training value. Stage A1 is the
opposite — trained at 640, run at **896** on the stitched frame
(`perception/fieldlib.py:67`), because the stitch is ~890 px tall and 640 would downscale it
by 0.72x.

This one masqueraded as a hardware difference for a while: "it gets 95 % on my colleague's
machine" turned out to mean "my colleague did not pass `imgsz`".

### `orange` reads as `plain`, or `apple` reads as `pineapple`

**Cause.** RGB input. Ultralytics' numpy path assumes the `cv2.imread` convention, i.e.
**BGR**. A PIL-read RGB array flips exactly these two pairs — both are colour-dominated
decisions.

**Action.** Convert with `arr[:, :, ::-1]` before `predict()`. If you are debugging a
classification regression, check this before touching the weights.

### Face inference is unexpectedly slow

**Cause.** Crops are being predicted one at a time.

**Action.** Batch all crops from a frame into a single `predict()` call. Measured with 5
crops: **10.9 ms batched vs 42.2 ms looped — 3.86x**.

### A cube at the edge of the frame is classified `plain`

**Cause.** The cube is cut off by the frame border, so its fruit face is partly or wholly
outside the image and only side faces remain — and by the arena's construction, side faces
*are* plain. The model is not wrong about what it can see.

**Status.** A known limitation: there is no border-contact detection, so a clipped cube is
judged on the faces that remain visible. If you add it, suppress the identity decision for
border-touching detections rather than forcing a class.

### The scan sees ghost cells, or misses cells it should see

**Action.** Do not debug this in the middle of a run. `match_runner.py` prints a
correct / wrong / ghost / missed table against the GT layout immediately after the scan,
before the robot drives anywhere — stop there. Then switch to data capture,
`field_autopilot.py record --mast down --gt-text "..."`, which saves raw top/near RGB+depth
pairs, the stitched YOLO overlay and a rosbag, and analyse offline.

Historical note: a doubling artefact that looked like a localisation problem turned out to be
depth under-estimation scattered along the line of sight. In-place rotation pose jitter was
only 1.5–2 cm, well inside the ±25 cm snap. The fix was grid-first snapping plus depth
back-projection plus a ≥3-vote requirement, which took an A/B set to 11 cells with 0 duplicates
and 0 misses. Nearby objects raise the wall-fit residual (`loc_score`, correlation −0.73) but
do **not** bias the pose.

### The model is right in the lab and wrong at the venue

**Cause.** Train/deploy domain gap. This cost us the qualifiers: the apple printed on the
arena objects was a **yellowish, under-ripe apple**, not the red one announced beforehand.
Every training image came from Blender, where the apple was red. The face model mis-predicted
it, and no amount of runtime tuning recovers a colour prior that was never trained.

**Action.** Photograph the *actual* objects at the *actual* venue, and fine-tune. That is
what we did between the qualifiers and the finals, on 2026-07-24: the face model that ran in
the finals was fine-tuned on real arena photographs. The fine-tuning recipe is
`perception/training/train_face_ft.py`.

### The robot approaches the object but stops short or overshoots

**Cause.** Range measured from the silhouette's bottom edge (`--range-mode ground`) assumes
the lowest visible pixel touches the floor. For round objects — and for any object whose
visible face is above the floor — it does not. Numerical cross-check: at a true floor point,
`ground` and `depth` agree to 0.0 mm; at 4 cm and 7 cm above the floor, `ground` over-estimates
by **+27–32 mm** and **+53–64 mm**. That bias produced unnecessary defensive hops, and after
the hop the contact point was outside the frame, so re-measurement failed every time — 0/4
icosahedron grasps on 2026-07-20.

**Action.** `--range-mode depth` is the default. Watch the `[approach]` log line: a high rate
of `src=ground` fallback means depth is returning holes (check alignment and the depth
profile, §4), not that `ground` is fine.

---

## 6. Gripper and mast

### The gripper node died mid-match — fixed the morning of the finals

**What happened.** At 05:12 on 2026-07-24 the bridge died on a `termios.error(5, 'Input/output
error')` raised out of `reset_input_buffer` during a USB re-enumeration. The handler caught
`OSError` and `serial.SerialException`; `termios.error` is neither, so it escaped `rclpy.spin()`
and ended the process, and nothing restarted it. A whole practice run collected zero objects.

**The three layers that went in before the finals:**

- The bridge now catches `termios.error` alongside `OSError`/`SerialException` at every serial
  call site — open, close, write, the `STATUS?` request and the read — and reconnects instead of
  dying (`hardware/ros2/robot_hardware/robot_hardware/gripper_bridge_node.py`, `SERIAL_ERRORS`).
- The node is launched with `respawn=True, respawn_delay=2.0`, matching the LiDAR driver on the
  same launch file.
- `field_autopilot.py up` treats the board as required and runs `ensure_gripper_alive()` before
  giving up: clear orphan duplicates, wait out the launch respawn, kick the launch child, start a
  standalone as a last resort.

**What that did *not* fix, and what actually happened in Final 1.** The process stayed alive all
match; the OpenRB simply stopped replying to the grasp check. Since 07-23 the runner only aborts a
grasp on an *active* `empty` verdict — silence is logged as `grasp_unconfirmed` and the cycle
continues, which is the right trade against an intermittently flaky board and exactly the rule that
carried an empty hand across the arena. The open item is a positive liveness requirement on the
verdict itself, not another restart mechanism.
- On shutdown the node re-opens the gripper when `open_on_shutdown` is enabled, which would
  drop a held object. `hardware/ros2/robot_bringup/config/real.yaml:117` sets it to `false`,
  so that path was not armed for the competition — but check it before you enable it.

**Action if you are building on this.** Wrap `rclpy.spin()` so that only clean shutdowns exit,
add `respawn=True` to the gripper node in the launch, and make the mission layer treat a
gripper-state timeout as a recoverable state rather than assuming the bridge is alive. None of
those three changes are in the code as it stands.

**Before you go looking for a software cause, check the boot order.** Every one of these
failures starts with the USB link to the OpenRB going away. Two physical things made that
much rarer for us and neither is in the code: booting the Jetson with the 12 V kill switch
**off** ([§2](#the-openrb-is-missing-or-drops-out-after-booting-with-12-v-live)) and running
both microcontrollers behind a powered USB hub
([`wiring-and-firmware.md` §2](../hardware/docs/wiring-and-firmware.md#2-boards-buses-and-who-owns-what)).

### `LIFT_*` does nothing

**Causes, in the order they actually occurred.**

1. **The kill switch is off**, so the OpenRB is unpowered and does not enumerate at all. This
   was the entire cause on 2026-07-21 and it looks exactly like a dead board.
2. **The board's firmware is not running** — no boot banner on the serial link. Re-flash
   (`hardware/bringup_tools/`) and confirm `READY`.
3. **Home was never captured.** Mast home lives in the board's RAM and is captured on the
   first lift command after boot. Any DTR reset (see §2) loses it. Confirm `home_set` in
   `/lift/state` before commanding the mast.
4. **You are in a mode that never calls it.** `match_runner.py --gt-map` deliberately does not
   raise the mast, because that mode skips the scan. Pass `--mast-up` if you want it raised
   anyway. The code logs "not a fault" for this case.

### Mast motion is reported as finished too late, or too early

**Cause.** Polling `LIFT_STATUS` alone over-estimated the raise as 13.5 s against a measured
~7 s.

**Action.** `lift_wait_idle(timeout, assume_done_s)` completes on whichever comes first: an
observed `MOVING == 0`, or the elapsed-time budget (7 s up, 6 s down), and returns the reason
it used. Non-blocking callers pass only the remaining budget measured from the command
timestamp, so parallel driving time is not counted twice.

### A held object is dropped when placing, or the fingers hit the storage wall

**Cause.** Commanding a full `OPEN` at the storage box makes the fingers collide with the box
wall. Commanding an absolute angle is also wrong: when the gripper holds an object the fingers
stop at the object's width, not at `closed_deg`, so the same absolute target produces a
different opening per object.

**Action.** Release **relative to the measured present position**: `--release-ticks 600` in competition, 450 by default (≈52.8° and 39.6°; an earlier build used 400) from
`present_deg` as reported on `/gripper/state`, tunable with `--release-ticks`. No firmware
change is needed — the bridge still sends `SET_DEG`.

### Grasp success is always reported as failed

**Cause (historical, fixed).** The `/gripper/grasp` payload key is `state`, and the mission
code read `grasp_state`, so it always saw an empty string and judged every grasp a failure —
including successful ones. `perception/fieldlib.py` now reads both keys for compatibility.

**Cause (configuration).** Grasp detection is sensorless — there is no force or tactile sensor
on this gripper. It compares the settled finger position against the commanded close. The
threshold has a measured basis (2026-07-17): an empty close settles at a gap of **3.0–3.2°**,
a gripped icosahedron at **14.1°**, so `grasp_pos_gap_deg: 8.0` sits mid-way with ~5° of
margin on both sides. Motor current is *not* usable as the primary signal — empty reads
107–113 raw and gripped reads 120 raw, both saturated — so it is only a secondary check
(`grasp_current_raw_min: 60`). The verdict is taken in a 0.25 s window 0.6 s after the close,
because the position curve goes dead flat at ~577 ms empty / ~537 ms gripped
(`hardware/ros2/robot_bringup/config/real.yaml:121-133`).

Objects much thinner than 8° of finger travel will not be detected. Re-measure `open_deg` /
`closed_deg` for your own gripper (`:119-120`) after any mechanical change.

### The grasp is consistently a centimetre short or long

**Action.** `GRIP_FORWARD_M = 0.115` (`perception/fieldlib.py:78`) is the measured forward
creep at which the gripper's front plate contacts the object. It is a single source of truth
shared by the mission code. Adjust it in ±0.01 steps; do not scatter local offsets.

---

## 7. Match-level

### The 3-minute clock ran out mid-grasp — it cost us the last object of Final 2

**What happened.** In Final 2 the timeout hit while the robot was grasping the last object.
The run was correct, just not finished.

**Action if you are building on this.** The speed profiles exist for this
(`safe` / `normal` / `fast`, at 0.5 / 0.8 / 0.95 m/s drive speed), and the shipped procedure
is to escalate: one `safe` cycle to prove the scan table and the grasp, then a full `normal`
run, then a full `fast` run, and adopt the fastest profile that keeps the success rate while
finishing inside 180 s. What is *missing* is a time-aware policy — the state machine has no
notion of "do not start a cycle that cannot finish". Compare `summary.total_sec` and the
per-cycle `route` / `approach` / `grasp` / `carry` phase times in `report.json` when tuning.

### The robot collects an object that is not the target

**Cause.** Target selection uses the scan's identity. If the class is confidently wrong, the
wrong object gets collected.

**Action.** `--target-class` re-verifies the object immediately before the close: A1 + face
(+ pair verifiers) are re-run at the final measurement, and only a **definite contradiction**
causes a skip — a polyhedron class mismatch, "not a cube", or a different fruit face at
conf ≥ 0.3. `plain`, no detection, and a weak fruit face all pass, because the arena's objects
show plain on every side face, so treating "undecidable" as a mismatch would discard genuine
targets.

**Watch out for the silent fallback.** If no cell is confidently the target class,
`pick_target` quietly reverts to nearest-first collection. If collecting a non-target costs
points under your rules, that fallback is a liability — make it explicit.

---

## 8. When none of this helps: capture, do not guess

```bash
python3 mission/field_autopilot.py record --mast down --gt-text "apple:150,200;..."
# drive the robot around with the UI or teleop, Ctrl-C to stop
python3 mission/field_autopilot.py down
```

`logs/field_ops/<timestamp>_*/` then holds everything needed for offline analysis:

| Artefact | Contents |
|---|---|
| `verdict.json` | the automatic pass/fail from `up` / `check` |
| `frame_<n>_{top,near}_{rgb,depth}.png` | raw pairs — depth is `uint16` mm, PIL mode `I;16` |
| `yolo_debug_<n>.png` | stitched frame with A1 + face overlays, confidences and face votes |
| `frames.jsonl` | per-frame pose, localisation latency, detections |
| `bag/` | rosbag of scan, arena status, motor, odometry, IMU, gripper, lift, `cmd_vel` |
| `gt.json` | the layout the operator typed in |

Always save the **raw top/near pair**, never only the stitched image. Almost every perception
question we could not answer afterwards was a case where only the stitch had been kept.

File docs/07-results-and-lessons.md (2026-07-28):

# Results and Lessons

This page is the record: what the robot scored, what we measured while building it, and the three
ways it failed in front of judges. The failures are documented at the same level of detail as the
wins, because they are the part of this repository that is hardest to get anywhere else.

**Full competition run (official video): `<YOUTUBE_URL>`**

---

## 1. The result

Team 14 placed **1st of 16 teams** at the SNU AI ROBOT CHALLENGE 2026.

Sixteen teams entered. The qualifiers are scored as a weighted pair — the first round counts for
10 % and the second for 90 % — and we scored 60 in both. Five teams advanced. The final standing is
the plain sum of two matches, 200 points maximum, with ties broken in favour of the faster mission
completion.

### Final standings

| | Team | Final 1 | Final 2 | Total |
| ---: | --- | ---: | ---: | ---: |
| **1** | **Team 14** | 60 | 90 | **150** |
| 2 | Team 7 | 70 | 70 | 140 |
| 3 | Team 8 | 80 | 30 | 110 |
| 4 | Team 16 | 0 | 100 | 100 |
| 5 | Team 10 | 30 | 20 | 50 |

The margin was **10 points**, but the number that mattered to us was our own spread: **60 and 90**,
with no collapse in either match.

That was the design goal, not luck. A robot that refuses uncertain objects, re-verifies a target
before closing on it, and treats a wrong pickup as costing double gives up the occasional perfect
run in exchange for never scoring near zero. Consistency across both matches is what the whole
refusal-to-guess design was buying, and it is what the final standing rewarded.

<p align="center">
  Team 14 with the winners' placard and the robot at the SNU AI ROBOT CHALLENGE 2026
</p>

### Our two finals

| | Target classes | Collected | Score |
| --- | --- | --- | ---: |
| Final 1 | octahedron · pineapple | 3 fruit cubes | 60 |
| Final 2 | octahedron · banana | 3 shapes + 3 fruit cubes | 90 |

Scoring is 10 points per shape object and 20 per fruit cube, so a perfect match is 100 — four shapes
and three fruit cubes. Nothing we ran was ever close to that, and two of the four matches lost
points to causes that had nothing to do with recognition accuracy.

---

## 2. Measured numbers

Everything below was measured on the real robot or on real captured data unless the row says
otherwise. Numbers we never measured are not in this table.

### Localisation and control

| Quantity | Value | Where measured |
| --- | --- | --- |
| Full known-map scan matching (the generic occupancy-grid matcher, as inherited from the Nav2/AMCL era) | **345–449 ms** per solve, with pose yaw jumping and the driven path bending | 2026-07-04 22:54 run on the real robot; this measurement is why the general matcher — and Nav2 with it — was dropped in favour of `wall_range` |
| `wall_range` localiser, synthetic 1080-beam scan | **20.35 ms** (32 beams, ~272 coarse+refine candidates) | `navigation/ros2/arena_lightweight_control/arena_lightweight_control/map_localization.py` |
| Same localiser, standalone / on the Jetson Orin Nano | **8–10 ms / 41 ms** against a 50 ms budget | `arena_control_node`, `localization_warn_latency_ms` watchdog |
| Localisation error, synthetic scan | **2 cm** after the short-return fix (**65 cm** before it) | short returns were being discarded as occlusions; the scan plane at 0.32 m is above every 8 cm object, so nothing can occlude a wall — they are penalised instead |
| Pose jitter during in-place rotation | **1.5–2 cm** | street-dataset A/B analysis, 2026-07-18. The grid snap tolerance is ±25 cm, so this is absorbed for free |
| Drive envelope on the arena floor | **1.22 m/s** at PWM saturation, **0.9 m/s** operational, strafe **0.6 m/s** (~90 % transfer through the rollers), **2.9 rad/s** rotation | motor bringup sweeps, `hardware/bringup_tools/53_max_speed.py` |

### Perception

| Quantity | Value | Where measured |
| --- | --- | --- |
| Stitch calibration residual, FHD-native, mast up | **0.78 px RMS**, max 1.26 px over 6 manual correspondences; fitted rotation +0.479°, scale 1.0085/0.9921 | `perception/calibration/stitch/up.json` (`residual_px`), fitted 2026-07-21 04:59 |
| Seam quality before/after calibration (640-era fit, 22 fresh pairs) | seam ΔY **+12.4 → +0.8** px; left/right disparity **5.56/5.88 → 1.59/1.16** px | live re-shoot with `perception/tools/stitch_calibrator.py --report` |
| A1 object segmenter, `val = train` | box mAP50 0.9941 / mAP50-95 0.9784 — **a meaningless number, published to show why** | Ultralytics validation on the training split |
| A1 object segmenter, held-out arena set (60 scenes, 573 objects) | **box mAP50 0.831 / mAP50-95 0.729; mask mAP50 0.821 / mAP50-95 0.558** | purpose-built mimic-arena eval set, 2026-07-08 |
| Face model, real 70-crop holdout (`topfruit_face_s_v3ft`, the shipped weight) | fruit **43 ok / 6 wrong-confirm / 1 missed**; plain **17 ok / 3 false-fruit** | real arena crops with hand-checked ground truth |
| Face model, same holdout, previous standard (`preferred_v2`) | fruit 35 ok / 13 wrong-confirm / 2 missed; plain 15 ok / 5 false-fruit | same set, same script (`perception/eval/face_model_compare.py`) |
| Face inference batching | **5 crops: 10.9 ms batched vs 42.2 ms looped — 3.86×** | Ultralytics `predict()` on the Orin Nano |
| 2-stage pipeline vs the earlier 4-stage ABC cascade, identical 30 s CPU capture | **3.83 FPS (259.9 ms/frame) vs 1.29 FPS (713.7 ms/frame)** — 2.97× | fair same-capture comparison, 2026-07-02 |
| Asymmetric fruit voting (5 sessions, 361 detections) | plain majority vote identified **1** fruit cube; K ≥ 2 faces at conf ≥ 0.5 identified **9**; K = 1 identified 10 but flipped an octahedron on a single false positive | offline re-tally over 5 real capture sessions; the rule shipped as `CELL_FRUIT_K`/`CELL_FRUIT_CONF`, `perception/fieldlib.py:70-71` |
| Full-frame YOLO inference on the robot | **43 ms ≈ 23 FPS** | Jetson Orin Nano, stitched frame |

### Grasping

| Quantity | Value | Where measured |
| --- | --- | --- |
| Grasp discrimination — settled finger-position gap | **empty hand 3.0–3.2°, holding an icosahedron 14.1°**, threshold **8.0°** (≈5° of margin on both sides) | hardware measurement 2026-07-17; `grasp_pos_gap_deg` parameter in `gripper_bridge_node` |
| Servo current as a grasp discriminator | **useless** — current-based position mode saturates at ~113 raw with an empty hand vs 120 held. Demoted to a "torque is alive" gate (≥ 60) | same session |
| Grasp settling time | **577 ms empty / 537 ms held** → the whole check shrank from 1.3 s to **0.85 s** per pick | settling-curve capture; fits inside the firmware's 3 s auto-open watchdog |
| Camera mount plane fits (4 measured mounts) | **0.9–2.7 mm RMS**, each cross-checked with a tape measure | `perception/fieldlib.py:41-46` |

### Sim / real parity (Isaac Sim, kinematic surrogate only)

Physics was never validated in simulation — that was a deliberate policy, and physical validation
happened on the robot. What the simulator *was* used for is running the unmodified field runner
end to end, and reproducing photometry.

| Quantity | Value | Where measured |
| --- | --- | --- |
| Sim floor-band luminance after the lighting sweep | sim **Y 109.8 / 109.5** vs real **107.6 / 113.8**; p99 **166 / 165** vs real 152–167; saturation **0 %** | `simulation/scripts/lowlight_lighting_sweep.py`, converged at key 331.9 / fill 232.3 |
| Isaac renderer: DLSS → DLAA | top-camera detection range **1.9 m → 3.0 m** — DLSS's half-resolution upscale destroys 14–30 px far objects | `/rtx/post/dlss/execMode=3` |
| Isaac renderer: auto-exposure histogram left on | image Y pinned at ~**205** regardless of lighting changes, silently cancelling the whole sweep | fixed with `/rtx/post/histogram/enabled=false` |
| Depth ranging in a full sim run | **100 % of measurements came from depth**, 0 ground-plane fallbacks; a 0.530 m measurement → 0.13 m defensive hop → re-measured 0.411 m (predicted landing 0.40 m) → grasp succeeded | 2026-07-21 parity session |
| Full E2E run in sim (run 4) | 28/28 cells scanned in 24 s, 3 collection attempts, **2 grasped / 2 placed**, COLLECT phase 108.9 s | same session, same `mission/match_runner.py` that ran on the robot |

### The last full rehearsal on the real robot

Run `20260721_155127`, the best of five consecutive E2E runs on the real arena the evening before
the competition (`--votes-k 1 --fruit-k 1 --range-mode depth --pair off`, speed profile `normal`):

| Metric | Value |
| --- | --- |
| Cells scanned from one centre point with an 8 × 45° spin | 28 |
| Correct against hand-entered ground truth | **23** |
| Wrong identity | 5 |
| Ghost cells (detected where nothing is) | **0** |
| Missed cells | **0** |
| Collection attempts / grasped / placed | 3 / 2 / 2 |
| Total time | **180.4 s** against a 180 s budget → verdict `PARTIAL` |

All five identity errors were fruit-vs-fruit: 2 × orange→apple, 2 × pineapple→apple, 1 × orange→plain.
Zero ghosts and zero missed cells means **detection and localisation were solved; identity was not.**
That single line predicted the competition: everything we lost, we lost to fruit identity, to the
clock, or to a crash — never to "the robot could not find the object".

---

## 3. The three failures

### 3.1 Qualifiers — the apple was the wrong colour

**What happened.** The apple printed on the arena's fruit cubes was a **yellowish, under-ripe
apple**. The pre-competition description said red. Our face model, trained on ~48 k web-sourced
fruit cutouts of which the apple pool was overwhelmingly red, mis-predicted it.

**Root cause.** A textbook train/deploy colour domain gap, and one we had already been warned
about by our own data. The whole spring was spent fighting apple↔orange confusion in the *other*
direction: the renderer's apple red-band HSV clamp ran *before* the per-channel BGR gains, so
gains re-leaked apple hue into the orange band (measured 50 % leakage before the fix, 0.0 % after,
over 200 strong-jitter trials). We fixed the renderer's colour handling but never questioned the
*premise* — that "apple" means "red".

**The fix that should have existed.** Not a better model. A **colour-agnostic apple**: the apple
texture pool should have been sampled across ripeness (green, yellow-green, yellow-red, red) the
same way the orange pool was rebuilt to 4,643 cutouts after the realism-asymmetry finding. The
hue-bucket ablation we ran on 2026-07-02 shows we had exactly the tool for this — it moved apple's
"orange" dominant-hue bucket from 166 to 109 and "yellow" from 13 to 4. We used it to *narrow* the
apple distribution. It should have been used to widen it along the ripeness axis while keeping
the orange band clamped. Cost: one re-render.

There is also a rules-level lesson: the target fruit is announced **one minute** before the match.
A domain gap you discover at the start signal cannot be fixed by retraining. Any part of the
pipeline that depends on an assumption about the physical objects has to be robust before you walk
into the venue, or exposed as a flag you can flip in 60 seconds.

### 3.2 Final 1 — the gripper stopped answering

**What happened.** The three pineapples went perfectly: routed, verified, grasped, carried, placed.
Then the OpenRB-150 went quiet. Cycle 4 approached an octahedron, closed, and got **no verdict at
all** from the grasp check — so, by the rule we had chosen the evening before, the robot carried on
and released an almost certainly empty hand over the box. Cycles 5 and 6 approached two more
octahedra and this time the board did answer, `empty`, twice each, so both were skipped. A seventh
was grasped and dropped in at 189.8 s — past the buzzer — and the runner then died in `rclpy` on
the retreat move. **60 points official; the run's own estimate was 70, counting the unconfirmed
placement.**

**Root cause — and what was already fixed.** A different gripper failure had hit us at 05:12 that
same morning: a `termios.error` raised from `reset_input_buffer` that our `except (OSError,
serial.SerialException)` did not catch, killing the node with nothing to restart it. That one we
diagnosed from its traceback and fixed before the finals, in three layers:

1. The bridge swallows `termios.error` at all five serial call sites and reconnects, instead of
   letting it escape as a fatal exception.
2. `respawn=True, respawn_delay=2.0` on `gripper_bridge_node`, matching the LiDAR driver that had
   taught us the lesson first.
3. Bring-up refuses to declare the stack healthy unless the gripper board actually answers, and
   tries a four-step self-heal before giving up: clear orphan duplicates, wait out the launch
   respawn, kick the launch child, and only then start a standalone bridge.

So Final 1 was **not** the failure we had already fixed. The process stayed alive the whole match;
the board simply stopped replying. What decided the outcome was a policy choice, not a missing
supervisor. On the evening of 07-23 we narrowed what counts as a failed grasp: only an *active*
`empty` verdict triggers the retry-then-skip, while silence is recorded as `grasp_unconfirmed` and
the cycle proceeds. That was the right trade against an intermittently flaky OpenRB — it stops one
dropped reply from costing a 25-second round trip — and it is exactly the rule that carried an
empty hand across the arena in cycle 4.

**The fix that should still exist.** Not a respawn; we have one. A *positive* liveness requirement
on the grasp verdict itself: treat "no answer" as its own state rather than folding it into "carry
on", and demand a fresh reply within the 0.85 s the check already takes. Silence should cost one
cycle, not one placement. The mast re-home caveat stays either way — reopening the OpenRB tty
toggles DTR, which reboots the board and wipes the RAM-held lift home, so any restarted bridge must
re-capture floor-home before it accepts a `LIFT_*` command.

### 3.3 Final 2 — ran out of time

**What happened.** The 180 s timeout expired while the robot was grasping its last object. That
object was already worth points on the field but scored zero, because only what is inside the
storage box at time-up counts.

**Root cause.** The budget was never comfortable and we knew it. The last full rehearsal finished
at **180.4 s** — over budget — and the run report has an explicit overrun flag for exactly this
reason (`summary.match_budget_sec = 180`, `mission/match_runner.py:2067`). Seven objects in 180 s
is ~25 s per object including the scan; we were running at three attempts per match.

Where the time went, from the instrumented phase timings:

- **In-place rotation.** Every rotation costs seconds *and* degrades yaw estimation (LiDAR smear
  during the turn, mecanum slip in odometry). The 2026-07-21 leg-alignment rewrite already cut
  this: instead of snapping the body to the cardinal direction of travel (up to 180° of rotation),
  it aligns to the nearest of `yaw + k·90°` — at most 45°, skipped entirely inside ±15°, on legs
  shorter than 0.35 m, on the final leg, and anywhere in the object-free bottom highway.
- **Dead-zone parking.** When the arena controller's approach deceleration falls below the
  firmware's PWM dead zone, the robot parks 0.17–0.35 m short of the goal and burns the full 25 s
  timeout. Measured three times in one match = 75 s lost. Fixed by a stall detector (no 3 cm of
  progress in 1.0 s → early exit to the caller's fallback) and by widening the goal tolerance to
  0.25 m so the last few centimetres are absorbed by the next phase instead of by a settling grind.
- **Rotate-then-strafe at the storage box.** Fixed on 07-22, and it is where the robot got its
  kick. The carry no longer stops to turn: `drive_drift()` sends the translation toward staging and
  the yaw command for −135° **at the same time**, so the robot slews into the storage heading while
  it is still crossing the arena and arrives already square-on to the lip. The receiving side had
  always been ready — `MecanumController.compute_command()` emits `(vx, vy, wz)` together in its
  `holonomic_drive` phase and the goal message parses an optional `yaw` — the caller simply never
  filled it in until then. Two rounds of tuning followed: dedicated drift gains
  (`--drift-yaw-rate 1.5`, `--drift-kp-yaw 2.5`, against 0.8/1.5 for ordinary driving) because the
  ordinary yaw rate was the floor on a 135° turn, and then a two-stage gain that drops back to the
  driving values once the heading error is inside 15°, because holding the aggressive gain to the
  end made the robot zigzag and smeared the LiDAR scan.

---

## 4. What did not work

Three ideas that looked obviously correct, were built, were measured, and lost.

### 4.1 The pair verifiers made accuracy worse

The design was appealing: after the 5-class face model votes, run a *binary* specialist on the
warped face patch — apple-vs-orange, banana-vs-pineapple — as a second opinion. Both verifiers
trained well (AO val acc 0.9826, BP val acc 0.9784) and both fixed the specific failure they were
built for in isolation (the real bunch-printed banana cube went from `pineapple 0.758` to
`banana ≥ 0.996`, 4/4 correct; bunch-holdout flip rate 25.02 % → 0.00 %).

Then we ran the full sweep on the robot's own data: **780 configurations** (verifier choice × gate
style × vote threshold) evaluated on **175 real face patches** from full street-capture frames.

| Configuration | Face-level accuracy |
| --- | --- |
| **Verifier OFF** | **85.7 %** |
| AO `v2_anchor` + asymmetric gate | 74.3 % |
| AO `v2` + asymmetric gate | 71.4 % |

The cell-level metric was useless for deciding: 144 of 780 configurations scored a perfect 22/22,
so it had no discriminating power at all — which is itself the methodological lesson. At face
level the gate cost 11 percentage points, and the mechanism was specific: the banana/pineapple
head kept flipping **correct** bananas to pineapple, taking that error class from 3 to 9–11. On a
separate holdout the ranking held (OFF 86.7 %, best). The result directly contradicted our own
integration guide, which had been written from a curated 155-crop set; we published the
contradiction rather than the assumption, and shipped `--pair off`.

A late repeat on 2026-07-24 over 771 accumulated real crops confirmed it from the other direction:
a retrained AO verifier changed only **5 identities (0.6 %)** versus the old one, and the gate was
observed swapping orange→apple **48–49 times** — the exact direction we were trying to fix.

**Lesson.** A component that is more accurate in isolation can still be a worse *decision rule* in
the system, because it fires on the cases the primary model already got right. Evaluate the gate,
not the classifier. And when your headline metric saturates, it is not a good metric.

### 4.2 The distance gate was only hiding a bug

`cube_too_far` rejected cubes whose mask short side fell below a pixel threshold, on the reasoning
that far-away cubes produce unreadable faces and unresolved noise. Raising the threshold visibly
cleaned up the output, so the recommendation was to raise it to 100 px or more.

Then we found the two runtime contract violations — the face model was being called at
`imgsz=640` (it is trained at 224, and 640 collapses confidence from ~0.9 to 0.1–0.4) and being
fed PIL's RGB array instead of cv2 BGR (which flips orange↔plain and apple↔pineapple). After fixing
both, we re-ran the same sweep over 5 sessions and 361 detections:

| `short_side` threshold | ≈ distance | `cube_too_far` | unresolved | fruit observations |
| ---: | ---: | ---: | ---: | ---: |
| **45 px (default)** | 1.09 m | 113 | **4** | **27** |
| 70 px | 0.70 m | 202 | 0 | 16 |
| 100 px | 0.49 m | 244 | 0 | 8 |
| 130 px | 0.38 m | 256 | 0 | 5 |

The "unresolved noise" the gate existed to clean up went from 69 to 4 without the gate doing
anything — it was never distance, it was the inference bug. With the bug gone, raising the
threshold only destroyed good information: fruit observations collapsed 27 → 5, and grids whose
best class was `plain` were wholesale relabelled `cube_too_far`. The recommendation inverted.

**Lesson.** A threshold that "cleans up" your output is a suspect. Before tuning it, verify that
the thing it is cleaning up is noise rather than a defect upstream of it. We tuned a gate for
three weeks against a symptom of a two-line bug.

### 4.3 Ground-contact ranging

To measure how far away an object is, the approach code back-projected the **lowest pixel of the
object's silhouette** onto the known floor plane. For a cube resting on the floor this is exact:
the bottom of the silhouette *is* the ground contact.

For a sphere-like polyhedron it is not. The lowest silhouette point is a tangent **in the air**,
so the back-projection lands beyond the true contact and the range comes out systematically long:
**+27 to +64 mm predicted at object heights of 4–7 cm, +5 to +10 cm measured.** That was enough to
push measurements past the 0.50 m defensive-hop threshold. The old hop then landed the robot at
~0.25 m, where the near camera (forward 0.187 m, height 0.314 m, tilt 53.2°, 42° vertical FoV) can
no longer see the contact point at all — so re-measurement failed **5/5** and the robot achieved
**0/4 icosahedron grasps** on 2026-07-20.

The fix reads the **depth median at the contact pixel** (sampled 3 px above it, scaled by
resolution/640, valid range 0.1–4.5 m), which is shape-independent. Ground-plane back-projection
is kept only as a fallback for invalid depth pixels, and its value is still logged every time as
`y_ground_ref` so the bias keeps being measured rather than assumed gone. The hop landing was
moved to 0.40 m, the median of the 0.36–0.51 m band where measurements actually succeeded. Both
paths remain selectable via `--range-mode depth|ground`.

**Lesson.** The assumption was true for the class we tested with, and the class we tested with was
the one that had the most objects. Geometry that is exact for one shape family and silently biased
for another is worse than geometry that is approximate for both, because the failure is invisible
in aggregate metrics.

### 4.4 Three smaller negatives, stated for the record

- **A low-LR extra fine-tune of the A1 detector** gained **+0.0002** on the (leaky) validation
  split and lost **1.5–2.5 pp on every held-out metric**. Rejected.
- **EfficientNet-B0 instead of MobileNetV3-Small** for the pair verifier: render-only 6/15 real
  oranges (worse), +anchor 12/15 (exact tie), at ~2.5 ms vs 0.95 ms on ONNX-Runtime CPU. The
  bottleneck was data, not capacity.
- **Five round-1 retrained face models** scored 0.858–0.9024 mask mAP50-95 on synthetic
  validation and **all five lost on the real robot** (21/22 for the incumbent vs 16–18/22). Root
  cause: every render machine used the same default seed and image ids, so only ~22.8 k of 53.7 k
  scenes were unique and duplicates leaked across the train/val split. Per-machine seeds fixed it.

---

## 5. Transferable lessons

1. **Delete the framework when the prior is strong enough.** A known empty 4 × 4 m square does not
   need AMCL. Closed-form ray/rectangle intersection against the four walls is ~30 float operations
   per beam and solved in 20 ms where full scan matching took 345–449 ms — in pure Python, with no
   numpy in the hot path. The win was not optimisation; it was refusing to solve the general problem.
2. **Exploiting a prior has a price, and you must pay it explicitly.** The same square that makes
   localisation cheap makes it 4-fold ambiguous. That cost us whole rehearsal runs until we made
   yaw *known* by integrating gyro-z forward between scans — after which the x/y solution is unique
   and can be re-solved globally every scan instead of tracked in a fragile local window.
3. **Publish your `val = train` numbers.** Our A1 detector read 0.9941 box mAP50 on the split it was
   trained on and 0.831 on a purpose-built held-out set. Both numbers are in the model card. The
   0.9941 is the more useful one, because it is the number that would have fooled us.
4. **Measure the decision, not the component.** The pair verifiers were more accurate than the face
   model at their own binary task and made the system worse. The distance gate improved a metric
   while destroying information. In both cases the component-level number was real and irrelevant.
5. **Runtime contracts are part of the model.** `imgsz=224` and BGR input are not implementation
   details — violating either silently halves the system's accuracy while every log line still
   looks healthy. They belong in the model card, in an assert, and in the integration test.
6. **Batch, don't loop.** 5 crops through one `predict()` call: 10.9 ms. The same 5 crops in a
   Python loop: 42.2 ms. Nothing about the model changed. Most of our 43-experiment runtime
   optimisation burst was frame-level batching, not model swaps.
7. **Instrument every motion, including the ones you think are free.** In-place rotation was
   originally unmeasured, which is exactly why it never appeared in the bottleneck report — while
   being the largest single time sink *and* the dominant cause of localisation collapse.
8. **Sensorless does not mean unmeasurable.** The gripper has no force sensor and its current
   reading is useless (empty-hand current saturates at ~113 of a 120 goal). The settled
   *position gap* — 3.0–3.2° empty vs 14.1° held — separates cleanly with ~5° of margin on each
   side. Look for the signal your actuator already produces.
9. **A three-minute match is a systems problem, not an algorithms problem.** We lost Final 2 to the
   clock while holding an object. Model loading is overlapped with operator input and driving; the
   mast raise overlaps a driving leg; the mast lower overlaps batch inference. Every one of those
   is worth more than a point of mAP.
10. **Write down why a constant has its value.** Nearly every threshold in this repository carries
    the date and the field observation that produced it. Those comments are the reason this
    document could be written at all, four days after the competition, from code rather than memory.

---

## 6. Read next

- [`docs/01-competition-and-rules.md`](01-competition-and-rules.md) — the constraints these results were produced under
- [`perception/docs/models.md`](../perception/docs/models.md) — the two runtime contracts in full
- [`navigation/README.md`](../navigation/README.md) — the localiser that replaced Nav2

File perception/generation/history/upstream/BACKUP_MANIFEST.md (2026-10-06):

# Backup Manifest

Last backup: 2026-05-16 (Asia/Seoul)

This repository is intended to preserve everything needed to reconstruct the AI robotics YOLO data-generation and training workflow, without committing the bulky generated image datasets.

## Git State

- Local branch: `main`
- Remote: `https://github.com/jaeyoungi2006/Data_Generation_Blender.git`
- Local backup base before this manifest: `6d0f7f6b9c24c2d4a9d9697e20e36e7b012862f4`
- Merged remote school updates from: `origin/master` at `2666d29297b432a8e979ecc4eee63b46a0356e7b`

## Tracked Recovery Assets

- Source scripts: `scripts/`
- Generated OBJ assets: `assets/generated/`
- Example email config: `config/email_smtp.example.json`
- Conda environment export: `environment.yml`
- Main README: `readme.md`
- YOLO dataset metadata:
  - `datasets/yolo_8class_maxobj5_balanced2_10000/data.yaml`
  - `datasets/yolo_8class_maxobj5_balanced2_10000/splits/front5000.yaml`
  - `datasets/yolo_8class_maxobj5_balanced2_10000/splits/front5000_train.txt`
  - `datasets/yolo_8class_maxobj5_balanced2_10000/splits/front5000_val.txt`
- Training metadata:
  - `runs/detect/runs/yolo_train/yolo11n_front5000_fast_b64/args.yaml`
  - `runs/detect/runs/yolo_train/yolo11n_front5000_fast_b64/results.csv`
- Model checkpoints:
  - `weights/best.pt`
  - `weights/yolo11n_front5000_fast_b64_best.pt`

## Checkpoint Integrity

Both tracked checkpoint files are identical.

```text
SHA256: AB44018B768C7CCB0B3F08FD31769337D88EDF15CB567F46800FB45C25A2CBE5
File: weights/best.pt
File: weights/yolo11n_front5000_fast_b64_best.pt
```

## Local Dataset Snapshot

These data files are intentionally ignored by git because they are large, but the current local machine has:

```text
datasets/yolo_8class_maxobj5_balanced2_10000/images/train: 7410
datasets/yolo_8class_maxobj5_balanced2_10000/labels/train: 7410
datasets/fruit_textures/detection_crops_512/apple: 1000
datasets/fruit_textures/detection_crops_512/banana: 1000
datasets/fruit_textures/detection_crops_512/orange: 1000
datasets/fruit_textures/detection_crops_512/pineapple: 1000
datasets/backgrounds/coco2017/val2017: 5000
```

Approximate local bulky data size:

```text
datasets/: 2661.9 MB
runs/:      90.21 MB
weights/:   40.58 MB
```

## Reconstruct From Git

```powershell
git clone https://github.com/jaeyoungi2006/Data_Generation_Blender.git
cd Data_Generation_Blender
conda env create -f environment.yml
conda activate ai_robotics
```

If the environment already exists:

```powershell
conda env update -n ai_robotics -f environment.yml --prune
conda activate ai_robotics
```

Regenerate assets if needed:

```powershell
python scripts\make_polyhedron_objs.py
```

Download/prepare backgrounds and fruit textures using the scripts under `scripts/`, then run one of the pipeline scripts:

```powershell
powershell -ExecutionPolicy Bypass -File scripts\run_yolo_50000_pipeline.ps1
```

For a smaller continuation from the current 8-class setup, follow `readme.md` and use:

```powershell
python scripts\run_yolo_parallel.py --num_images 10000 --workers 10 --cpu_threads 1 --output datasets\yolo_8class_maxobj5_balanced2_10000 --samples 16 --max_objects 5 --scale_min 0.40 --scale_max 2.45 --negative_ratio 0.22 --fruit_texture_dir datasets\fruit_textures\detection_crops_512 --resume
```

## Verify Model

```powershell
Get-FileHash weights\best.pt -Algorithm SHA256
```

Expected SHA256:

```text
AB44018B768C7CCB0B3F08FD31769337D88EDF15CB567F46800FB45C25A2CBE5
```

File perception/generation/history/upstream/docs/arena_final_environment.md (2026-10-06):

# 경기장 최종 환경 사양 (2026-07-08 기준)

출처 우선순위: ① 경기장 최종 공지 (2026-07 실물 완성) ② 실물 사진 2장 + 천장 조명 사진 ③ 공식 룰북 v2.0 (`jetson/AI 로봇 챌린지 공식 룰북.txt`). 공지/실물이 룰북과 다르면 공지/실물이 우선.

## 위치

- 39동 지하 2층 (실내, 창 없음 — 천장 조명이 유일 광원)

## 바닥 (Floor)

- 크기: **4m × 4m** 정사각형
- 재질: 나무 합판 + **SUN-111(베이지 샤벨)** 라미네이트 — 실물은 따뜻한 우드 톤에 세로 방향 나뭇결이 뚜렷함 (사진 기준 결이 큰 티크/월넛풍 스트라이프)
- **여러 플레이트로 분할 제작** → 플레이트 간 미세 단차/이음선 존재, 투명 시트지로 덮음 (약한 광택 반사 가능)

## 담벼락 (Fence)

- 높이: **290mm** (룰북 300mm에서 공지로 수정), 두께 약 15~20mm 합판
- 재질: 룰북은 "무광 흰색 아크릴"이었으나 실물은 **SUN-168(페인트 베이지)** 계열 밝은 베이지 우드 라미네이트 (사진: 미세한 수평 나뭇결)
- **이음부 알루미늄 플레이트 결합** — 코너/이음부에 금속 플레이트가 안쪽으로 조금 튀어나옴 (사진: 코너 세로 방향 알루미늄 판 + 볼트)

## 주요 구역

- **출발 구역 (Start Zone)**: 우측 하단, 40cm × 40cm. 로봇 시작 위치 (초기 자세 자유)
- **보관함 (Storage Zone)**: 좌측 하단 코너, 외곽 40cm × 40cm
  - 좌측 벽 + 하단 벽이 경계, 나머지 2면은 3D 프린팅 턱 (폭 10mm, 높이 3mm)
  - 실물 사진에서는 **검은색 경계선(테이프/턱)** 으로 사각형 표시
  - **깃발(태극기 스티커) 표시**: 벽면에 약 6장(두 벽에 나눠 부착), 구역 안 바닥에 4장 — 소형 직사각형 스티커
- 적재 판정: 위에서 봤을 때 경계 밖 돌출 시 불인정, 적층 허용

## 조명 (Lighting)

- 천장: 산업용 콘크리트(밝은 회백색) + 은색 HVAC 덕트/케이블 트레이, 천장고 높음 (수 m)
- **원형 고천장(high-bay) LED 4개가 직사각형 배치**, cool-white(주광색) — 천장 사진 기준
- 룰북상 조명 제한 없음 → 실측 기준으로 재현

## 물체 (Objects) — 총 28개

- 공통: 3D 프린팅, 기본 흰색, **눕혔을 때 높이 8cm**, 3D 모델 별도 제공
- 세트 1 (형상): 정육면체/정팔면체/정십이면체/정이십면체 각 4개 = 16개 (개당 10점)
- 세트 2 (이미지): 정육면체 12개 = 과일 4종(사과/오렌지/바나나/파인애플) × 3개 (개당 20점)
  - **3개 면에만 실제 과일 사진 인쇄 부착** (면마다 다른 사진 가능, 단 동일 클래스), 나머지 3면은 흰 면
  - 세트 1 정육면체와 크기·색 동일 → 외형만으로 세트 구분 불가
- 배치: 랜덤, **물체끼리 비접촉**, **벽 접촉 허용**, 출발 구역에서 **최소 60cm** 이상
- 경기장 밖 이탈 물체는 되돌리지 않음

## 경기장 밖 환경

- 실물: 공방/작업장 (콘크리트 바닥, 선반, 박스, 셔터문 등 잡동사니) — 합성 시 **COCO 이미지를 펜스 바깥 배경으로 배치**해 다양화

## 경기 요약 (참고)

- 3분 단독 기록 경기, 완전 자율, Jetson Orin Nano 필수, 카메라 비전 필수, 외부 연산 금지
- 당일 오전 목표 1종 공지(세트별), 오픽업 2배 감점, 최대 100점(세트1 4개 + 세트2 3개)
- 로봇 크기 40cm³ 이내 → 카메라 높이는 지면 ~40cm 이하 (low robot view 근거)

## 재현 파라미터 요약 (Blender)

| 항목 | 값 |
| --- | --- |
| 바닥 | 4.0×4.0m, SUN-111 우드 나뭇결, 플레이트 이음선 1~3개, 투명시트 약광택 |
| 펜스 | 높이 0.29m, SUN-168 베이지, 코너 알루미늄 플레이트 |
| 보관함 | (0,0) 코너 0.4×0.4m, 검은 테두리 턱 10mm, 태극기 스티커 벽 6/바닥 4 |
| 출발구역 | 반대편 코너 0.4×0.4m (시각 표식은 실물 미확인 — 표식 없음으로 재현) |
| 조명 | 원형 area light 4개 직사각 배치, cool-white(~5000-6500K), 높이 3~5m |
| 물체 | 28개 (도형 16 + 과일큐브 12), 높이 8cm, 비접촉, 벽접촉 허용 |
| 카메라 | 로봇 시점 (높이 ≤0.4m), 경기장 내부 |
| 외부 | 펜스 밖 COCO 배경 |

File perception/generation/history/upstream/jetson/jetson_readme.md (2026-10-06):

# Jetson Runtime Readme

이 파일은 예전 링크 호환을 위해 남겨둔 짧은 안내 문서입니다.

Jetson Orin Nano runtime의 기준 문서는 [README.md](./README.md)입니다. 해당 문서에는 다음 내용이 들어 있습니다.

- 필요한 weights와 model aliases
- 첫 webcam 실행
- overlay 의미
- target options
- ABC cascade fallback
- Jetson에서 TensorRT export하는 방법

빠른 실행:

```bash
./jetson/run_webcam_preview.sh \
  --pipeline unified \
  --camera 0 \
  --camera-backend v4l2 \
  --device 0 \
  --target-shape cube \
  --target-fruit apple \
  --print-model-output
```

주의: `preferred-unified`를 full frame에 직접 실행하지 마세요. 반드시 `--pipeline unified`를 사용해 A1이 `cube_like_object`를 먼저 crop하게 해야 합니다.

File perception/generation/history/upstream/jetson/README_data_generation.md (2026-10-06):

# Data Generation Notes

이 파일은 짧은 안내용 pointer입니다. `jetson/` 폴더는 Jetson Orin Nano runtime 실행을 위한 폴더이며, 전체 training history를 보관하는 위치가 아닙니다.

데이터 생성과 학습 관련 내용은 아래 root 문서를 보세요.

| 문서 | 역할 |
| --- | --- |
| [../readme.md](../readme.md) | 현재 구조, 빠른 시작, 판단 로직 |
| [../readme_specific.md](../readme_specific.md) | 기술 reference, threshold, dataset 계보, 과거 기록 |
| [../EXPERIMENTS.md](../EXPERIMENTS.md) | 실험 상태 기준 색인 |

Jetson runtime 주요 파일:

```text
jetson/realtime_seg_cam.py
jetson/abc_inference.py
jetson/run_webcam_preview.sh
jetson/run_webcam_preview.ps1
jetson/ABC_model/
```

새 모델을 학습한 뒤 Jetson에서 테스트하려면 검증된 runtime candidate만 `jetson/ABC_model/` 아래 새 explicit folder로 복사하세요. preferred weights를 조용히 덮어쓰면 안 됩니다.

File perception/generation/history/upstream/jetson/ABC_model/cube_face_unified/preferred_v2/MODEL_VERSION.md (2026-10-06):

# cube-face unified preferred_v2 (Face Classifier)

기준일: 2026-07-08 (sparse-icon 120-epoch 본 학습 완료·승격)

이 폴더의 `weights/best.pt`는 Jetson runtime에서 `face-classifier`(구 `preferred-unified`) alias로 로드되는 현재 preferred Face Classifier입니다. 파일명은 `best.pt` 유지.

현재 bundled weight는 **sparse printed-icon booster mix로 120 epoch fine-tune한 정식 run의 best (epoch 47, patience 35로 82에서 조기종료)** 입니다. 앞서 승격했던 30-epoch 프로브와 통계적으로 동급이며(아래 비교), 완전 수렴된 정식 run이라 이것으로 최종 확정했습니다.

## Source

```text
runs/segment/cube_face_unified_yolo26n_seg_sparse_icon_from_readd_adamw_lr1e5_ft_v1/weights/best.pt
```

## Lineage

```text
... -> hsv_pruned_coloroutlier -> readd_coloroutlier_base (epoch 83)
  -> sparse_icon_from_readd probe30 (epoch 16, 중간 승격)
  -> sparse_icon_from_readd 120ep 본학습 (best epoch 47)  <- 현재
```

## Training Summary

- Init: readd_coloroutlier_base best (직전 preferred)
- Data: `datasets/cube_face_unified_finetune_readd_plus_sparse_icon_10k_v1` — train 77,099 = readd mix 64,604 + sparse-icon booster 12,495 (`realistic_a4_sparse_icon`: patch 0.24~0.40 + posterize + webcam_hard, 10k scenes) / val 7,893
- AdamW lr0=1e-5, lrf=0.05, cos_lr, warmup 0, batch 512, imgsz 224, workers 4, cache=disk, epochs 120 (patience 35 → 82에서 stop, best 47), 7.1h
- ONNX 재수출 완료 (opset 20, imgsz 224). `best.engine`은 Jetson에서 재빌드 필요.

## Validation / Hard-Set Snapshot

mix val (best epoch 47): all mask mAP50/mAP50-95 `0.967 / 0.894`, box `0.968 / 0.924`. orange mask mAP50 0.953.

직전 preferred(readd) 및 중간 probe30과의 hard-set 비교:

| 지표 | readd best | probe30 (ep16) | **120ep (ep47, 현재)** |
| --- | --- | --- | --- |
| recorded 실물 orange (평가 전용, 86 crops) | 65.1% | 96.5% | **95.3%** |
| orange-apple margin p10 | -0.385 | +0.121 | **+0.111** |
| arena v3 probe apple / orange | 68.8 / 69.7% | 75.0 / 75.8% | **81.2 / 78.8%** |
| mix val mask mAP50-95 | 0.894 | 0.893 | **0.894** |
| blank 저신뢰 fruit 오탐 | 14/25 | 16/25 | **17/25** — runtime ambiguity guard(≥0.4) 필수 |

probe30과 120ep은 recorded 1 crop 차이(노이즈)로 사실상 동급이며, 120ep이 arena에서 소폭 우세. 목표(recorded 80%)를 두 모델 모두 크게 초과.

리포트: `reports/cube_face_unified_eval/recorded_hardset_120ep_20260708/`(작성 예정), `arena_v3_probe_100_v1_top_class_120ep/`, `sparse_icon_probe_iterations_20260708/summary.md`

## File Hash

```text
SHA256 1203602222BDBB3A353844E57BD75AFCB6088280C4FEDF9583B902BA907BAC3E weights/best.pt
SHA256 934B5DAF36F3C9E68FB823AFBD6DC735A1C6646D8F40BCBA3D366D528F24C444 weights/best.onnx
```

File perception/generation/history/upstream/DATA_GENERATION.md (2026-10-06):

# 데이터 생성 로직 (완전판)

기준일: 2026-07-08

이 문서는 **"학습 데이터를 왜/어떻게 이렇게 만들었나"** 를 설명하는 현행(living) 기준 문서입니다. 2026-07-02 문서 재작성 때 삭제됐던 데이터 생성 로직 전체를 [docs/history/readme_specific_full_20260702.md](./history/readme_specific_full_20260702.md)(삭제 직전 완전판, 105KB)에서 복원해 현재 기준으로 재정리했습니다. 아카이브는 원문 그대로 보존되고, 이 문서가 앞으로 유지보수되는 기준입니다.

- 프로젝트 개요/런타임 구조: [readme.md](../readme.md)
- 실험 상태 색인: [EXPERIMENTS.md](../EXPERIMENTS.md) / 모델 계보 서사: [HISTORY.md](../HISTORY.md)
- 학습/배포 기술 reference: [readme_specific.md](../readme_specific.md)

표기 원칙: 여기 나오는 CLI 옵션은 2026-07-08 기준 `scripts/run_yolo_parallel.py`, `scripts/generate_yolo_coco_composite.py`에 실제로 존재하는지 확인했습니다. 옵션은 유지되지만 예시 명령의 출력 경로/클래스 구성이 옛 세대(8-class)인 경우 **"구버전 기준"** 으로 표시하고 삭제하지 않습니다.

## 1. 철학과 원칙

이 프로젝트는 단순히 예쁜 synthetic image를 만드는 것이 아니라, 실제 카메라에서 들어올 수 있는 불완전한 장면을 견디는 YOLO 모델을 만들기 위해 설계했습니다. 핵심 목표는 다음과 같습니다.

```text
1. 대회 환경의 class 정의를 그대로 반영한다.
2. 실제 촬영 데이터가 적어도 재생성 가능한 합성 데이터로 빠르게 보강한다.
3. 합성 이미지는 다양하게 흔들되, 라벨은 최종 렌더에서 실제 보이는 픽셀만 사용한다.
4. 과일 texture가 보이지 않는 cube를 과일로 학습시키지 않는다.
5. 작은 object, 프레임 밖 object, 과도한 occlusion, 얇은 sliver label을 줄인다.
6. 흰색 물체와 배경에서 생기는 false positive를 negative sample로 억제한다.
7. 생성 결과를 preview와 metadata로 사람이 빠르게 검수할 수 있게 한다.
8. 대형 데이터는 Git에 넣지 않고, 코드와 설정만으로 재생성 가능하게 남긴다.
```

설계의 큰 방향은 **"이미지는 다양하고 지저분하게, 라벨은 보수적이고 깨끗하게"** 입니다. 카메라 노이즈, 조명, blur, JPEG artifact, 배경 변화는 일부러 강하게 넣지만, 학습 target은 ideal geometry visibility map 또는 BlenderProc `instance_segmap` 기반으로 계산해서 사람이 그린 bbox보다 일관되게 만듭니다. 최종 학습용 생성은 ideal geometry visibility gate를 우선 사용합니다.

가장 중요한 운영 규칙(visibility 철학 원문):

```text
숨겨진 과일은 분류하지 않는다.
cube-like object는 plain cube 확정이 아니다.
과일 cube는 Task 1에서도 cube처럼 보일 수 있다.
Task 1 cube pickup은 한 view만 보고 확정하지 않는다.
보이는 fruit face crop만 fruit class evidence로 사용한다.
```

즉 **보이는 픽셀만 라벨링하고, fruit face가 보이지 않으면 fruit로 학습시키지 않습니다.** 이 원칙은 데이터 생성(fruit 라벨 fallback)과 런타임 판단(`cube_like_unresolved`) 양쪽에 똑같이 적용됩니다.

### 데이터 설계 판단

과일은 실제 3D mesh 대신 cube 위의 texture로 구현했습니다. 대회에서 실제 물체가 "과일 사진이 붙은 흰색 cube"에 가깝고, 모델이 과일의 3D 형상보다 cube 면에 붙은 2D 과일 이미지를 보고 분류해야 하기 때문입니다.

- fruit cube에는 **3개 면에만** 과일 texture overlay를 둡니다. 한 cube의 fruit class는 하나로 고정합니다(apple cube면 3개 면 모두 apple texture).
- 기본 생성은 한 이미지 안에 서로 다른 fruit class의 cube가 같이 나올 수 있고, 한 cube의 3개 면도 같은 class 안에서 서로 다른 source texture를 쓸 수 있습니다. 필요하면 `--single_fruit_class_per_image`, `--single_fruit_texture_per_cube`로 예전처럼 강하게 묶을 수 있습니다.
- 이 overlay는 별도 helper object로 segmentation에 잡히며, 이를 통해 "cube 전체가 보였는지"와 "과일 사진 면이 실제로 보였는지"를 따로 계산합니다.
- 과일 texture는 class별 색상 score로 1차 필터링합니다. `collect_fruit_textures()`는 class별 대표 색상 조건을 통과하는 이미지를 캐시하고, banana는 작은 cube에서 pineapple처럼 보이는 초록 다발 texture를 기본 후보에서 제외합니다. alpha가 있는 누끼 texture는 흰 배경 위에 합성해서 사용합니다.
- texture 파일의 선언 class가 cube class와 다르면 생성 단계에서 **즉시 실패**시키고, `_meta/*.json`에 face별 texture 경로와 class를 기록합니다. 한 cube 안에 다른 fruit class가 섞이는 것(poison data)을 코드 수준에서 막는 장치입니다.
- 흰색 polyhedron은 PLA 출력물처럼 보이도록 off-white 색상과 roughness를 랜덤화합니다. 완전한 순백색 하나만 쓰면 모델이 색상에 과하게 붙을 수 있기 때문입니다.

## 2. Visibility 정책 (수치 기준)

### 2.1 지표 정의

preview와 `_meta/train/*.json`에는 visibility 지표가 들어갑니다.

```text
obj_vis =
  ideal 또는 segmap 기준으로 보이는 object mask 픽셀 수
  / 화면 밖과 occlusion을 반영한 full projected object 면적

fruit_vis =
  ideal 또는 segmap 기준으로 보이는 fruit face mask 픽셀 수
  / 화면 밖과 occlusion을 반영한 full projected cube 면적
```

`obj_vis`는 object 자체가 얼마나 보이는지, `fruit_vis`는 fruit cube에서 과일 사진 면이 얼마나 보이는지를 봅니다. 비율만으로는 충분하지 않습니다 — 이미지 전체에서 과일 사진 면이 너무 작으면 학습 신호가 약하기 때문에 **절대 픽셀 수 기준**도 같이 사용합니다.

### 2.2 Fruit 라벨 기준과 fallback

fruit cube는 아래 기준을 **모두** 통과해야 과일 class로 라벨링됩니다.

```text
fruit_vis >= 0.10
visible fruit face pixels >= 300
visible fruit face bbox width >= 10 px
visible fruit face bbox height >= 10 px
target visibility tier == actual visibility tier
```

기준을 통과하지 못한 fruit cube는 과일 class로 학습시키지 않고 `cube`로 fallback됩니다. preview에서는 아래처럼 표시됩니다.

```text
cube  from=banana  fallback
```

fallback의 의미는 "처음에는 banana texture가 붙은 cube였지만, 최종 렌더에서 banana 사진 면이 충분히 보이지 않아 banana 라벨 대신 cube 라벨로 쓴다"입니다.

이 정책이 필요한 이유: 과일 texture가 거의 보이지 않는 장면을 과일 class로 학습시키면 모델이 흰 cube의 모양이나 배경 힌트만 보고 과일 class를 예측하게 됩니다. 그런 샘플은 과일 분류 학습에는 해롭지만 cube 검출 학습에는 여전히 유용하므로 버리지 않고 `cube`로 돌립니다.

`_meta/train/*.json`에는 `source_class`, `fallback_class`, `fruit_visibility_pass`, `visible_face_pixels`, `visible_face_bbox`, `visible_face_segments`가 남아, preview에서 fallback 이유를 눈으로 확인할 수 있고 threshold를 바꿀 때도 원인을 추적할 수 있습니다.

### 2.3 Visibility tier 정의와 비율

fruit visibility tier는 과일 면이 항상 정면으로 잘 보이는 데이터만 생기지 않도록 만든 장치입니다.

```text
easy: 과일 면이 크게 보이는 장면
mid:  과일 면이 부분적으로 보이는 장면
hard: 과일 면이 작거나 비스듬히 보이는 장면
```

구현상 `easy`는 작은 tilt, `mid`는 더 큰 tilt, `hard`는 완전 random rotation에 가깝습니다. scale도 tier별로 조정합니다(easy는 조금 크게, hard는 조금 작게).

tier 혼합 비율과 `fruit_photo_cube_ratio`(projected object 면적 대비 과일 사진 면 비율) 기준:

```text
easy 50%: fruit_photo_cube_ratio 0.50 이상
mid  45%: fruit_photo_cube_ratio 0.20~0.50
hard  5%: fruit_photo_cube_ratio 0.10~0.20
```

hard tier에는 별도의 완화된 하한을 둡니다: `fruit_vis 0.10`, `fruit_face_pixels 900` (일반 기준은 각각 0.22 / 1800). hard sample은 필요하지만 주력 분포가 되면 안 된다는 실험 결론(§8) 때문에 5%로 억제합니다.

### 2.4 Ideal visibility gate

후보 배치 후에는 `--ideal_visibility` 단계가 한 번 더 있습니다. 비싼 Blender color render를 돌리기 전에 ideal geometry만으로 occlusion을 계산합니다. 각 mesh face와 fruit face helper를 카메라에 투영하고, 간단한 depth buffer로 앞에 보이는 instance map을 만든 뒤 다음 조건을 검사합니다.

```text
target fruit tier == actual fruit tier
obj_vis > 0.10
fruit_vis >= 0.10
visible fruit face pixels >= 300
visible fruit face bbox width/height >= 10 px
```

조건을 만족하지 못하면 color render 없이 배치를 다시 샘플링합니다. 기본 `--ideal_visibility_max_attempts`는 80입니다. 80번 안에 완벽한 배치를 찾지 못하면 마지막 후보를 사용하고 로그에 fallback을 남깁니다.

### 2.5 라벨 정책 (보이는 픽셀만)

- 어느 경로든(ideal gate 또는 `render_segmap()`) **라벨은 카메라에서 실제로 보이는 픽셀만** 사용합니다. 뒤쪽에 가려진 object 영역은 라벨에 포함하지 않습니다. 합성 단계에서는 object의 원래 3D 모양과 위치를 알고 있지만, 가려진 영역까지 라벨에 넣으면 모델은 이미지에 없는 물체 영역을 맞추도록 학습하게 됩니다.
- 같은 class의 object가 붙어 있어도 instance가 다르면 서로 다른 segmentation 라벨로 나뉩니다. `--seg_contour_mode largest` 기준에서는 object마다 가장 큰 외곽 contour 하나만 YOLO segment 라벨로 씁니다.
- occlusion 필터: `--min_object_visible_ratio 0.10` 이하인 object는 없는 object처럼 취급해서 라벨과 metadata에서 제외합니다. 또한 기본 `--max_covered_ratio 0.80`이므로 visible ratio가 `0.20`보다 낮은 후보 배치는 ideal gate에서 다시 샘플링됩니다. 아주 얇은 sliver 라벨을 학습시키지 않기 위한 기준입니다.
- contour 단순화는 OpenCV `approxPolyDP`, `--seg_contour_epsilon_ratio 0.01`을 사용합니다. 면적 오차 1%가 아니라 contour perimeter의 1% 정도를 경계 거리 오차로 허용한다는 뜻입니다. cube bevel, pixel stair-step, distortion remap 때문에 생긴 자잘한 contour 점을 줄이면서도 과일 면 경계가 무너지지 않는 균형값입니다.

## 3. 장면 / 카메라 / 렌더링 설계

### 3.1 장면 생성 설계

- object 수는 positive scene에서 `--min_objects`부터 `--max_objects` 사이로 샘플링합니다. 최종 학습 권장값은 `1~4`입니다. 너무 많으면 occlusion과 작은 라벨이 늘고, 너무 적으면 실제 난이도를 충분히 만들지 못합니다.
- object 위치는 완전히 균일하게 뿌리지 않습니다. 일부는 기존 object 근처에 배치해 겹침/근접 상황을 만들되, 중심 간 최소 거리를 둬서 모든 라벨이 무의미하게 겹치지는 않게 합니다.
- 각 object transform은 여러 번 시도합니다. **과일 object는 최대 300번, 일반 shape는 최대 120번** 후보를 평가하며, 후보 평가는 다음을 같이 봅니다.

```text
frame 안쪽 margin을 지키는지
projected object area가 충분한지
fruit face 예상 픽셀 수가 충분한지
fruit visibility tier 범위에 들어오는지
```

- 완벽한 후보를 찾지 못하면 가장 점수가 좋은 후보를 사용합니다. 생성이 멈추지 않으면서도 품질 기준에 가까운 장면을 계속 만들기 위한 설계입니다.
- `fruit estimated face pixels`는 `projected_object_area * fruit_photo_cube_ratio`로 계산합니다. fruit cube 전체가 커도 과일 사진 면이 너무 작게 보이면 좋은 후보로 보지 않습니다.
- 생성 단계 우선 조건: `projected object area >= 900 px`, `fruit estimated face pixels >= 300 px`, frame margin 준수, tier target 만족.
- negative sample은 흰색 cylinder/sphere distractor와 COCO 배경으로 구성됩니다. `category_id=0` background로 취급되어 라벨에 들어가지 않습니다. 목적은 "흰색 물체가 보이면 무조건 cube/polyhedron"이라고 외우는 것을 막는 것입니다.
- negative 여부는 `--negative_ratio`와 seed/image_id로 결정됩니다. 같은 seed와 image id를 쓰면 negative 여부가 재현되므로, 중간에 끊겼다가 `--resume`으로 이어도 데이터셋 성격이 크게 흔들리지 않습니다.

### 3.2 카메라와 렌더링 설계

- 카메라는 640x640 기본 해상도에서 lens, 위치, target을 매번 바꿉니다. lens는 넓은 화각부터 망원 느낌까지 흔들고, 카메라 위치는 tabletop/close-up 사이 느낌이 섞이도록 제한된 범위에서 샘플링합니다.
- 조명은 world color, key light, fill light, optional under light, optional ring light를 랜덤화합니다. warm/cool 색을 섞고, area/point/sun light를 섞습니다.
- 배경은 COCO 이미지를 crop해서 사용하며, 배경 자체에도 blur, gain/bias, 약한 texture noise를 넣습니다. 물체가 항상 깨끗한 studio background 위에만 놓이는 문제를 피하기 위함입니다.
- 렌더된 foreground는 COCO background와 합성합니다. object mask는 `soften_mask()`로 약간 부드럽게 만들어 지나치게 날카로운 synthetic edge를 완화합니다.
- 가짜 그림자도 일부 장면에 추가합니다(mask를 이동/blur 후 배경을 어둡게). 물리적으로 완벽한 그림자보다, 모델이 바닥/배경의 어두운 접촉부에 익숙해지게 하는 목적입니다.

### 3.3 카메라 artifact 설계

최종 이미지에는 실제 카메라에서 흔히 생기는 artifact를 일부러 넣습니다.

```text
channel gain 변화
밝기 gain/bias 변화
gamma 변화
Gaussian noise
Gaussian blur
수평/수직 motion blur
저해상도 down-up sampling
vignetting
JPEG compression
너무 밝거나 너무 어두운 이미지 보정
```

이 artifact는 **이미지에만 적용하고, 라벨은 artifact 전에 계산된 segmentation 결과를 기준으로 저장합니다.** 학습 이미지는 현실적으로 흔들리지만 라벨 좌표는 렌더 결과와 일관되게 유지됩니다. (현행 추가: `--camera_artifact_profile`로 강도 프로파일 선택 가능 — §10.1 참조.)

### 3.4 Lens distortion 설계

lens distortion은 무작정 적용하지 않습니다. distortion map이 원본 이미지 밖을 참조하지 않는 파라미터를 **최대 80번** 찾고, 안전한 파라미터를 찾은 경우에만 이미지, instance segmentation, background를 같은 map으로 remap합니다.

```text
distortion으로 인한 카메라 다양성은 유지한다.
distortion 후 생기는 검은 테두리나 crop/rescale로 segmentation label이 틀어지는 문제는 피한다.
```

안전한 distortion을 찾지 못하면 해당 이미지에는 distortion을 적용하지 않습니다. 품질을 깨면서까지 증강을 넣지 않는 쪽을 선택한 설계입니다. 적용 확률은 `--lens_distortion_prob`(기본 0.35)로 제어합니다.

이전에는 distortion 후 무효 영역을 crop하고 다시 640x640으로 키우는 방식이 있었지만(구버전), 현재 코드는 그 방식 대신 "안전 파라미터만 채택" 방식을 씁니다.

### 3.5 Frame margin 정책

object 자체가 프레임 밖으로 걸리는 문제도 따로 막습니다. object transform 샘플링 시 projected vertices가 화면 안쪽 margin에 들어오는 후보를 고릅니다. 현재 margin은 `0.08`입니다.

이 margin은 edge-touch label을 줄이기 위한 장치입니다. 물체가 가장자리에서 잘리면 segmentation 경계가 이미지 테두리와 붙고, 실제 object 크기와 라벨 크기 해석이 애매해집니다. 품질 체크리스트에서 `edge-touch labels = 0`을 목표로 두는 이유입니다.

## 4. Metadata 스키마

### 4.1 Meta V1 (`_meta/train/*.json`)

각 이미지마다 `_meta/train/{image_id}.json`을 저장합니다. 단순 로그가 아니라 품질 기준을 자동으로 검증하기 위한 설계 산출물입니다.

주요 필드:

```text
image_id
negative
label_format
fruit_visibility_tier
label_objects
fruit_objects
```

- `label_objects`: 실제 YOLO 라벨로 저장된 object의 class, visible pixel 수, projected area, object visible ratio, fallback 정보.
- `fruit_objects`: 과일 texture 면이 실제로 얼마나 보였는지, pass/fallback 판단 근거 (`fruit_visibility_pass`, `visible_face_pixels`, `visible_face_bbox`, `visible_face_segments`, `face_textures`, `fruit_visible_ratio`, `object_visible_ratio` 등).

이 metadata 덕분에 preview 수동 검수와 threshold 위반 샘플 자동 검수를 같이 할 수 있습니다. §7.4 품질 체크리스트가 단순 권장사항이 아니라 `_meta` 기반으로 확인 가능한 기준이 되도록 설계했습니다.

### 4.2 Meta V2 (`--meta_v2`, 현행 기준)

Meta V2는 A1/A2/B/C와 cube-face unified export의 기반이 되는 확장 스키마입니다(`--meta_v2` 옵션으로 생성). 저장되는 핵심 필드 7종:

```text
1. object visible/full mask        (보이는 영역과 가려지기 전 전체 영역 분리)
2. face visible/full mask          (cube face 단위 mask + visible_segments)
3. face quad_xy / quad_xy_raw      (occlusion이 없었다면 face가 가졌을 4점 quad / refinement 전 원본)
4. corner visibility               (face 꼭짓점 4개 각각의 실제 가시 여부)
5. occluder object ids             (누가 이 face를 가렸는지)
6. camera intrinsics/extrinsics    (카메라 내부/외부 파라미터)
7. scene/object transform          (scene_snapshot: object 3D transform, mesh geometry)
```

face 단위 항목에는 `face_kind`(fruit/plain), `fruit_class`, `visible_pixels`, `visible_ratio`, `quality`(good/partial/bad)가 같이 붙습니다. occlusion이 있어도 다음 정보가 분리되어 있는 것이 핵심입니다.

```text
visible_segments:   실제 이미지에서 보이는 face 영역만 표현
quad_xy:            occlusion이 없었다면 face가 가져야 하는 4점 quad
corner_visibility:  각 꼭짓점이 실제로 보이는지 여부
```

cube face 항목 예시(JSON):

```json
{
  "cube_faces": [
    {
      "object_name": "apple_000",
      "face_index": 0,
      "face_kind": "fruit",
      "fruit_class": "apple",
      "quad_xy": [[120, 130], [220, 126], [230, 230], [128, 236]],
      "quad_xy_norm": [[0.1875, 0.2031], [0.3438, 0.1969], [0.3594, 0.3594], [0.2000, 0.3688]],
      "visible_pixels": 2345,
      "visible_ratio": 0.73,
      "quality": "good"
    }
  ]
}
```

이 스키마 덕분에 새 Blender 렌더링 없이도 `datasets/meta_v2_50000_coco_texture_v1`의 `_meta`만 재조합해 unified cube-face dataset(94,210 crops)을 export할 수 있었습니다. quad/keypoint 후속 실험은 `quads/*.json` sidecar로 이어집니다.

## 5. 권장 기본값 (생성 CLI 옵션과 이유)

현재 추천 기본값은 코드와 맞춰 아래와 같습니다. 주의: 아래는 **권장값**이며, 일부는 코드 기본값과 다릅니다(예: `--min_fruit_face_pixels` 코드 기본값 300, 권장 1800 / `--min_fruit_visible_ratio` 코드 기본값 0.10, 권장 0.22). 재현 시 명령에 명시해야 합니다. 모든 옵션은 2026-07-08 기준 코드에 존재함을 확인했습니다.

| option | value | 이유 |
|---|---:|---|
| `--label_format` | `segment` | 현재 주력은 YOLO segmentation |
| `--seg_contour_mode` | `largest` | instance별 주 외곽만 사용 |
| `--seg_contour_epsilon_ratio` | `0.01` | bevel/픽셀 계단 contour 완화 |
| `--min_projected_area` | `900` | 너무 작은 object 생성 감소 |
| `--min_fruit_face_pixels` | `1800` | 과일 사진 면의 절대 정보량 보장 |
| `--single_object_scale_min` | `0.82` | object가 1개뿐일 때 너무 작은 fruit cube가 일반 cube처럼 보이는 문제 방지 |
| `--single_object_min_projected_area` | `2600` | 단일 object scene의 화면 내 최소 크기 상향 |
| `--single_object_min_fruit_face_pixels` | `2200` | 단일 fruit cube의 과일 사진 면 정보량 보장 |
| `--min_fruit_visible_ratio` | `0.22` | fruit label을 남길 때 필요한 과일 면 비율 |
| `--hard_min_fruit_visible_ratio` | `0.10` | hard tier에서만 허용하는 낮은 fruit visibility 하한 |
| `--hard_min_fruit_face_pixels` | `900` | hard tier에서만 허용하는 낮은 fruit face pixel 하한 |
| `--min_fruit_face_side` | `36` | 얇은 fruit face 라벨 방지 |
| `--min_object_visible_ratio` | `0.10` | obj_vis 0.10 이하 object는 없는 object로 취급 |
| `--max_covered_ratio` | `0.80` | ideal gate에서 과한 occlusion 배치 재샘플링 |
| `--negative_ratio` | `0.18` | 흰색/배경 false positive 방지 |
| `--samples` | `16` | 속도와 품질 균형 |
| `--min_objects` | `1` | empty positive scene 방지 |
| `--max_objects` | `4` | 과한 occlusion과 메모리 사용 방지 |
| `--scale_min` | `0.40` | 작은 object 다양성 유지 |
| `--scale_max` | `2.45` | 큰 object 다양성 유지 |
| `--lighting_mode` | `soft_overhead` | 한쪽 강한 광원보다 overhead soft + fill 중심 |
| `--arena_background_ratio` | `0.05` | 대부분 COCO 배경, 경기장형 배경은 5%만 섞음 |
| `--fruit_texture_dir` | `datasets/fruit_textures/final_fruits36065_original25_fruitseg30_10` | Fruits-360 65%, crawled/original 25%, FruitSeg30 10% 고정 pool |
| `--fruit_texture_aug` | `light` | class 색 의미를 보존하면서 face별 회전/확대/축소 |
| `--fruit_texture_layout` | `mixed` | single face texture와 same-class collage texture를 섞음 |
| `--fruit_texture_collage_prob` | `0.35` | `mixed` layout에서 face별 collage 사용 확률 |
| `--fruit_class_weight_scale` | `1.20` | 과일 class 등장 가중치 전체 배율 |
| `--fruit_visibility_easy_weight` | `0.50` | easy tier 50% |
| `--fruit_visibility_mid_weight` | `0.45` | mid tier 45% |
| `--fruit_visibility_hard_weight` | `0.05` | hard tier 5% |
| `--allow_mixed_fruit_classes_per_image` | enabled | 한 이미지 안에 서로 다른 fruit cube class 허용 |
| `--allow_multiple_fruit_textures_per_cube` | enabled | 한 cube의 3개 fruit face에 같은 class 내 다른 source texture 허용 |
| `--canonical_fruit_textures` | enabled | 검증된 canonical texture 경로만 사용 |
| `--train_low_aug` | enabled | YOLO 학습 augmentation이 fruit class 색을 다시 흔드는 것을 줄임 (`run_yolo26_seg_pipeline.py` 옵션) |
| `--ideal_visibility` | enabled | render 전에 ideal geometry로 배치 검증 |
| `--ideal_visibility_max_attempts` | `80` | 좋은 배치를 찾는 최대 시도 횟수 |

### Scale 분포: triangular distribution

scale은 균등분포로 뽑지 않습니다. 작은 object set은 유지하되 과하게 자주 나오지 않도록 **triangular distribution**(`random.triangular(lower, scale_max, mode)`)을 사용합니다. 여러 object가 있는 scene에서는 작은 object를 허용하고, object가 1개뿐인 scene에서는 scale 하한(`--single_object_scale_min 0.82`)과 projected area 하한을 올려 fruit cube와 plain cube가 너무 쉽게 헷갈리는 샘플을 줄입니다.

### Fruit class 가중치

과일 class는 조금 더 자주 나오도록 가중치가 있습니다 (`generate_yolo_coco_composite.py`의 `FRUIT_CLASS_WEIGHTS`, `--fruit_class_weight_scale`로 배율 조정):

```text
shape classes: 1.00
banana:        1.55
orange:        1.35
pineapple:     1.55
apple:         1.50
```

## 6. 텍스처 파이프라인

### 6.1 소스 준비 6단계

아래 대형 데이터는 Git에 올리지 않으므로 재생성/다운로드로 채웁니다. 가장 빠른 복구는 백업에서 `datasets/backgrounds/coco2017/`과 `datasets/fruit_textures/final_fruits36065_original25_fruitseg30_10/`을 그대로 복사하는 것입니다. 복사할 수 없으면 아래 순서대로 다시 만듭니다.

```text
assets/generated/
datasets/backgrounds/coco2017/
datasets/fruit_textures/_sources/fruits360_clean_256/
datasets/fruit_textures/_sources/original_color_filtered_512/
datasets/fruit_textures/_sources/fruitseg30_cutouts_512/
datasets/fruit_textures/final_fruits36065_original25_fruitseg30_10/
```

**1단계 — 기본 asset 생성** (다면체 OBJ):

```powershell
python scripts\make_polyhedron_objs.py --out assets/generated --size 0.08
```

**2단계 — COCO 2017 배경 다운로드** (`val2017`만 있어도 동작하지만, 최종 학습용은 `train2017`까지 받아 배경 pool을 크게):

```powershell
python scripts\download_coco2017_backgrounds.py --split val2017 --output datasets\backgrounds\coco2017
python scripts\download_coco2017_backgrounds.py --split train2017 --output datasets\backgrounds\coco2017
```

**3단계 — Fruits-360 source 준비** (Kaggle `moltean/fruits`):

```powershell
mkdir datasets\fruit_textures\_raw\kaggle_fruits360_download
kaggle datasets download -d moltean/fruits -p datasets\fruit_textures\_raw\kaggle_fruits360_download --unzip
python scripts\prepare_kaggle_fruits360_textures.py --clear
```

**4단계 — Crawled/original source 준비**: 기존 실험과 같은 결과를 원하면 `datasets/fruit_textures/_sources/original_color_filtered_512/`를 백업에서 복사합니다. 복사본이 없으면 Wikimedia 기반 대체 source를 만들 수 있으나, 웹 검색 결과가 바뀌므로 완전히 같은 pool은 아닙니다. 대체 source를 만들었으면 반드시 contact sheet로 잘못 들어온 과일을 제거합니다.

```powershell
python scripts\download_generic_fruit_textures.py `
  --output datasets\fruit_textures\_sources\original_color_filtered_512 `
  --per_class 400 `
  --clear
```

**5단계 — FruitSeg30 누끼 source 준비**: Mendeley public API에서 selected class만 내려받아 image/mask를 RGBA cutout으로 변환합니다. **apple source는 `Apple_Gala`만 사용하고 `Apple_Golden Delicious`는 제외**합니다.

```powershell
python scripts\prepare_fruitseg30_textures.py --clear --size 512
```

2026-05-20 기준 로컬 count: apple 65 / banana 82 / orange 83 / pineapple 65.

**6단계 — 최종 고정 texture pool 생성**: 생성기는 raw source를 매번 뒤지지 않고 final pool만 읽습니다.

```powershell
python scripts\make_mixed_fruit_textures.py --clear
```

출력: `datasets/fruit_textures/final_fruits36065_original25_fruitseg30_10/`

pool preview 확인:

```powershell
python scripts\make_texture_contact_sheets.py `
  --root datasets\fruit_textures\final_fruits36065_original25_fruitseg30_10 `
  --count 40 `
  --thumb_size 104 `
  --columns 8
```

`_preview_apple.jpg` / `_preview_banana.jpg` / `_preview_orange.jpg` / `_preview_pineapple.jpg`를 눈으로 검수합니다.

### 6.2 Production 비율 정책

class별 1,600장, 소스 비율은 **lab(Fruits-360) 65% / crawled·original 25% / FruitSeg30 10%** 로 고정합니다.

| source type | count per class | ratio |
| --- | ---: | ---: |
| lab (Fruits-360 clean) | 1040 | 65% |
| original_filtered (crawled) | 400 | 25% |
| fruitseg30 (누끼) | 160 | 10% |

apple/orange/banana/pineapple 각 1,600장. Fruits-360만으로는 studio domain이 강하고, crawling만으로는 품질이 흔들리므로 고정 final pool로 재현성과 다양성을 같이 확보합니다(§8 실험 발전 기록 참조).

Meta V2 50k 세대의 texture 정리(2026-06-23):

```text
production texture:  datasets/fruit_textures/production_meta_v2_50000_v1
base texture:        datasets/fruit_textures/final_fruits36065_original25_fruitseg30_10
archived experiment: datasets/fruit_textures/_archive_experimental_20260623_c_hardcase
```

웹에서 받은 orange hard texture는 production에 직접 섞지 않았습니다. ① `orange_hard_web_exp_001`에는 실제 orange가 아닌 이미지가 섞였고, ② orange-only 보강은 apple/orange balance를 무너뜨릴 수 있으며, ③ texture source 비율을 바꾸지 않고 render-time augmentation으로 다양성을 늘리는 편이 안전하기 때문입니다. ratio 변경은 report 없이 금지입니다 (canonical policy: `reports/texture_policy_meta_v2_50000_20260623.md`).

### 6.3 Texture 증강 수치

- `--fruit_texture_aug light`: 회전 ±22도, 배율 0.758x~1.32x
- `--fruit_texture_aug strong`: 회전 ±45도, 배율 0.588x~1.70x (구버전에서 사용하다 light로 하향 — §8 참조. 단 Meta V2 50k 세대는 `strong` + `mixed` + collage 0.35를 사용했음)
- `--fruit_texture_layout collage`: 같은 class 안에서 작은 과일 사진 여러 장을 흰 배경에 붙인 generated face texture 생성. collage patch ratio는 light 기준 0.52~0.70 (작은 patch는 class cue가 약해 상향 조정된 값)
- `--fruit_texture_layout mixed`: `--fruit_texture_collage_prob` 확률로 single/collage 혼합
- `print_label` layout과 프로파일 계열은 §10.1 참조 (현행 추가)

## 7. 운영 절차

### 7.1 설치 및 복구

```powershell
git clone https://github.com/jaeyoungi2006/Data_Generation_Blender.git
cd Data_Generation_Blender
conda env create -f environment.yml
conda activate ai_robotics
```

이미 환경이 있으면 `conda env update -n ai_robotics -f environment.yml --prune`. `blenderproc`가 PATH에 없으면:

```powershell
$env:PATH = "C:\Users\USER\anaconda3\envs\ai_robotics\Scripts;C:\Users\USER\anaconda3\envs\ai_robotics;$env:PATH"
```

### 7.2 100장 품질 검증 워크플로우

새 설정은 바로 대량 생성하지 않고 **100장을 새 폴더에 생성한 뒤 preview와 자동 지표를 함께 확인**합니다. synthetic data는 숫자 지표만 보면 좋아 보여도 실제로는 과일 면이 너무 작거나, contour가 깨지거나, 경계가 이상할 수 있기 때문입니다.

<details>
<summary>재현 명령 전문 — 100장 품질 검증 생성 (구버전 기준 출력 경로, 옵션은 현행 유효)</summary>

```powershell
python scripts\run_yolo_parallel.py `
  --num_images 100 `
  --workers 8 `
  --cpu_threads 1 `
  --output datasets\yolo_8class_seg_quality100 `
  --width 640 `
  --height 640 `
  --samples 16 `
  --min_objects 1 `
  --max_objects 4 `
  --scale_min 0.40 `
  --scale_max 2.45 `
  --negative_ratio 0.18 `
  --fruit_texture_dir datasets\fruit_textures\final_fruits36065_original25_fruitseg30_10 `
  --background_dir datasets\backgrounds\coco2017 `
  --arena_background_ratio 0.05 `
  --label_format segment `
  --seg_contour_mode largest `
  --seg_contour_epsilon_ratio 0.01 `
  --min_object_visible_ratio 0.10 `
  --min_fruit_visible_ratio 0.22 `
  --min_fruit_face_pixels 1800 `
  --single_object_scale_min 0.82 `
  --single_object_min_projected_area 2600 `
  --single_object_min_fruit_face_pixels 2200 `
  --min_fruit_face_side 36 `
  --fruit_visibility_easy_weight 0.50 `
  --fruit_visibility_mid_weight 0.45 `
  --fruit_visibility_hard_weight 0.05 `
  --hard_min_fruit_visible_ratio 0.10 `
  --hard_min_fruit_face_pixels 900 `
  --lighting_mode soft_overhead `
  --fruit_texture_aug light `
  --fruit_texture_layout mixed `
  --fruit_texture_collage_prob 0.35 `
  --allow_mixed_fruit_classes_per_image `
  --allow_multiple_fruit_textures_per_cube `
  --canonical_fruit_textures `
  --ideal_visibility `
  --ideal_visibility_debug `
  --ideal_visibility_max_attempts 80
```

중간에 끊겼으면 같은 명령에 `--resume`을 추가합니다.

</details>

출력 구조:

```text
datasets/yolo_8class_seg_quality100/
  data.yaml
  images/train/*.jpg
  labels/train/*.txt
  _meta/train/*.json
  ideal_visibility_debug/train/*.jpg
  _chunks/logs/*.log
```

검수 이미지는 두 종류입니다.

```text
ideal_visibility_debug/train/
  검은 배경 위에 ideal geometry visibility 계산 결과를 표시 (full silhouettes / visible objects / visible fruit faces)

visibility_preview/train/
  최종 합성 사진 위에 YOLO label, fruit_vis, obj_vis, OK/fallback을 표시
```

### 7.3 Preview 생성

```powershell
# 일반 segmentation preview
python scripts\make_yolo_bbox_preview.py `
  --dataset datasets\yolo_8class_seg_quality100 `
  --count 100

# visibility debug preview
python scripts\make_yolo_bbox_preview.py `
  --dataset datasets\yolo_8class_seg_quality100 `
  --count 100 `
  --debug_visibility
```

debug preview는 `visibility_preview/train/`에 생성되고, caption panel에 다음이 표시됩니다.

```text
#번호  class  tier=easy/mid/hard  fruit_vis=...  obj_vis=...  OK/fallback
```

preview는 이 프로젝트의 핵심 검증 도구입니다. `--debug_visibility`는 과일 면을 시각적으로 highlight해서 "왜 과일로 남았는지 / 왜 cube fallback이 됐는지"를 빠르게 확인하는 모드이며, **highlight는 preview 이미지에만 들어가고 학습 이미지에는 절대 들어가지 않습니다.**

### 7.4 품질 체크리스트

100장 생성 후 확인 항목:

```text
images / labels / metas 개수 일치
ideal visibility debug 100장 생성
negative_ratio와 empty label 개수 대략 일치
edge-touch labels = 0
projected object area < 900 라벨 = 0
fruit label visible_face_pixels < 1800 = 0, except hard tier floor 900
fruit label fruit_vis < 0.22 = 0, except hard tier floor 0.10
fruit label target tier != actual tier = 0
obj_vis <= 0.10 라벨 = 0
worker err log에 Traceback/Error/Exception 없음
visibility preview 100장 생성
```

검증 세트 `datasets/ideal_gate_100_test` 기준 결과 (기록):

```text
images / labels / metas: 100 / 100 / 100
ideal debug / preview debug: 100 / 100
empty non-negative labels: 0
label/meta mismatch: 0
obj_vis <= 0.10 labels: 0
fruit tier mismatch labels: 0
worker errors: 0
worker 1, 320x320 smoke timing:
  total 173.63s
  color render total 141.70s
  ideal geometry + debug + Python overhead 31.93s
  non-render overhead about 0.32s/image
```

품질 검증은 "완벽한 class 균등 분포"보다 **"라벨 오류를 만들지 않는 것"** 을 우선합니다. class 분포는 100장 단위에서 흔들릴 수 있지만, edge-touch, 너무 작은 라벨, 과일 면 부족, 과한 occlusion 같은 오류는 대량 생성 전에 반드시 잡아야 합니다. 생성 품질 자동 검사는 `scripts/audit_fruit_generation.py`가 담당합니다(mixed fruit class 허용 여부, cube별 texture metadata, face texture metadata 존재 확인).

### 7.5 병렬 생성 및 재시작 설계

`scripts/run_yolo_parallel.py`는 image id를 worker 수만큼 **round-robin chunk**로 나눕니다. 각 worker는 `_chunks/worker_###.txt`에 자기 id 목록을 받고, stdout/stderr는 `_chunks/logs/worker_###.*.log`에 따로 남습니다. 대량 생성 중 일부 worker가 실패했을 때 원인을 분리해서 보기 쉽고, 이미 생성된 이미지를 유지한 채 이어서 돌리기 쉽게 하기 위한 구조입니다.

`--resume`의 완료 판정 규칙: **이미지와 라벨 파일이 모두 존재하는 id만 완료**로 봅니다.

```text
images/train/000123.jpg exists
labels/train/000123.txt exists
=> image_id 123은 skip
```

metadata만 있고 이미지/라벨이 없거나, 이미지 하나만 있는 경우는 완료로 보지 않습니다. 생성 데이터셋의 최소 단위는 image와 label의 쌍이기 때문입니다.

진행률은 output 폴더의 image 개수 기준으로 계산합니다. 이메일 알림은 생성 실패를 막지 않도록 non-blocking으로 처리합니다 — SMTP 문제가 생겨도 데이터 생성은 계속 진행됩니다. worker가 죽으면 `--max_worker_retries 5`, `--retry_delay_seconds 30` 기준으로 재시도하며, `--process_chunk_size`로 짧은 수명의 BlenderProc 프로세스 여러 개로 쪼갤 수도 있습니다(장시간 실행 안정화).

### 7.6 50,000장 생성

최종 dataset은 50,000장 목표로 생성합니다. GPU/CPU 안정성이 우선이면 `--workers 10`부터 시작하고, 시스템이 안정적이면 16까지 올릴 수 있습니다.

<details>
<summary>재현 명령 전문 — 50,000장 생성 (구버전 기준 8-class 출력 경로/이메일 주소, 옵션은 현행 유효)</summary>

```powershell
python scripts\run_yolo_parallel.py `
  --num_images 50000 `
  --workers 16 `
  --cpu_threads 1 `
  --output datasets\yolo_8class_seg_v5_50000 `
  --samples 16 `
  --min_objects 1 `
  --max_objects 4 `
  --scale_min 0.40 `
  --scale_max 2.45 `
  --negative_ratio 0.18 `
  --fruit_texture_dir datasets\fruit_textures\final_fruits36065_original25_fruitseg30_10 `
  --background_dir datasets\backgrounds\coco2017 `
  --arena_background_ratio 0.05 `
  --label_format segment `
  --seg_contour_mode largest `
  --seg_contour_epsilon_ratio 0.01 `
  --min_object_visible_ratio 0.10 `
  --min_fruit_visible_ratio 0.22 `
  --min_fruit_face_pixels 1800 `
  --single_object_min_projected_area 2600 `
  --single_object_min_fruit_face_pixels 2200 `
  --min_fruit_face_side 36 `
  --fruit_visibility_easy_weight 0.50 `
  --fruit_visibility_mid_weight 0.45 `
  --fruit_visibility_hard_weight 0.05 `
  --hard_min_fruit_visible_ratio 0.10 `
  --hard_min_fruit_face_pixels 900 `
  --lighting_mode soft_overhead `
  --fruit_texture_aug light `
  --fruit_texture_layout mixed `
  --fruit_texture_collage_prob 0.35 `
  --allow_mixed_fruit_classes_per_image `
  --allow_multiple_fruit_textures_per_cube `
  --canonical_fruit_textures `
  --ideal_visibility `
  --ideal_visibility_max_attempts 80 `
  --email_to jaeyoungi@snu.ac.kr `
  --email_every 2000
```

재시작은 **같은 명령 전체에 `--resume`만 추가**해서 다시 실행합니다 (같은 seed/설정이어야 negative 여부 등이 재현됨).

생성 후 preview:

```powershell
python scripts\make_yolo_bbox_preview.py `
  --dataset datasets\yolo_8class_seg_v5_50000 `
  --count 100 `
  --debug_visibility
```

</details>

현행(Meta V2 세대) 50k 생성은 위 명령 대신 wrapper를 사용합니다 — 생성부터 A1/A2/B/C 학습까지 7단계를 묶은 것:

```powershell
conda activate ai_robotics
cd C:\Users\user\Documents\Data_Generation_Blender
powershell -ExecutionPolicy Bypass -File scripts\run_meta_v2_50000_training_pipeline.ps1
```

```text
1. Meta V2 COCO image 50,000장 생성      (source: datasets/meta_v2_50000_coco_texture_v1)
2. A1/A2/B/C dataset export               (datasets/meta_v2_50000_coco_texture_v1_models)
3. C unknown hard negative 추가
4. A1 YOLO26s-seg 학습                    (texture pack: datasets/fruit_textures/production_meta_v2_50000_v1)
5. A2 YOLO26n-seg 학습
6. B TinyQuadNet 학습                     (log: logs/meta_v2_50000_pipeline)
7. C MobileNetV3-Small 학습
```

50k generation의 texture 설정(2026-06-23 확정): `--fruit_texture_aug strong`, `--fruit_texture_layout mixed`, `--fruit_texture_collage_prob 0.35`.

참고: 8-class 시절 end-to-end 실험(생성→split→audit→preview→train→predict→side-by-side)은 `scripts/run_yolo26_seg_pipeline.py`가 담당했습니다(구버전 기준이지만 스크립트/옵션 유지). wrapper 기준값은 1,000장 `run_yolo26_seg_1000_pipeline.ps1`(train 800/val 100/test 100), 50,000장 `run_yolo26_seg_50000_pipeline.ps1`(train 40000/val 5000/test 5000, `--resume_generate`). 중간 단계 재개는 `--skip_generate --skip_split --skip_preview --skip_train --skip_predict --skip_side_by_side` 조합으로 합니다.

### 7.7 이메일 알림 설정

이메일 설정은 `config/email_smtp.json` 또는 환경 변수로 제공합니다. 비밀번호가 들어가므로 **Git에 올리지 않습니다** (예시는 `config/email_smtp.example.json`).

```json
{
  "host": "smtp.gmail.com",
  "port": 587,
  "user": "your_email@gmail.com",
  "password": "app_password",
  "from": "your_email@gmail.com",
  "tls": true
}
```

테스트와 생성 중 옵션:

```powershell
python scripts\send_progress_email.py `
  --to jaeyoungi@snu.ac.kr `
  --subject "Data Generation Blender test" `
  --body "SMTP test"
```

```text
--email_to <주소>
--email_every 2000     # 생성 이미지 2000장마다 1회, 시작/완료/오류 시 각 1회
```

메일 전송에 실패해도 데이터 생성은 계속 진행됩니다. 장시간 YOLO 학습 모니터링은 `scripts/monitor_yolo_training_email.ps1`, `scripts/send_yolo_50000_status_email_loop.ps1`(30분마다 results.csv 요약 발송)를 사용합니다. 학습 프로세스 자체를 메일 wrapper로 감싸지 않는 이유: `train_yolo_with_email.py`로 YOLO stdout을 감싸면 carriage-return progress 출력이 Windows pipe에서 멈추는 현상이 재현되어, **학습 프로세스와 메일 모니터를 분리**했습니다.

### 7.8 진행 상황 확인

```powershell
# 생성 개수
$ds='datasets\yolo_8class_seg_v5_50000'; `
$img=(Get-ChildItem "$ds\images\train" -Filter *.jpg).Count; `
$lbl=(Get-ChildItem "$ds\labels\train" -Filter *.txt).Count; `
"images=$img labels=$lbl"

# 관련 프로세스
Get-CimInstance Win32_Process |
  Where-Object {
    $_.Name -in @('python.exe','blenderproc.exe','blender.exe') -and
    $_.CommandLine -match 'run_yolo_parallel|generate_yolo_coco_composite|blenderproc'
  } |
  Select-Object ProcessId,Name,CommandLine

# GPU
nvidia-smi
```

## 8. 실험 발전 기록 (관찰 → 판단 → 조치)

지금 설정은 한 번에 나온 것이 아니라, confusion matrix와 preview에서 보인 실패 패턴을 줄이면서 정한 값입니다. 정확한 run 산출물 전체는 `runs/`와 `datasets/` 아래 대형 파일이라 Git에 올리지 않지만, 모델을 발전시킨 판단은 아래처럼 남깁니다.

| 단계 | 관찰된 confusion matrix 패턴 | 판단 | 다음 조치 |
|---|---|---|---|
| 초기 legacy YOLO/YOLO11 계열 bbox/seg 실험 | cube/polyhedron은 대각선이 비교적 강하지만 fruit cube class는 off-diagonal이 큼 | 과일상자 segmentation 자체보다 fruit label 분리가 병목 | 기본 모델을 `yolo26n-seg.pt`로 올리고 segmentation 중심으로 전환 |
| 과일 texture 변화가 거의 없는 50,000장 실험 | fruit box mask는 잘 잡지만 apple/orange, banana/pineapple, orange/apple 혼동이 큼 | 물체 검출은 배우지만 과일 사진 class cue가 좁음 | source texture 다양화와 face texture augmentation 도입 |
| `fruit_texture_aug strong` + 강한 색 변화 | fruit class off-diagonal이 줄지 않거나 일부 악화 | 색 변화가 class 고유 색까지 흔들어 라벨 의미를 흐림 | `fruit_texture_aug light`로 낮춤 |
| train 기본 augmentation | YOLO 학습 augmentation이 synthetic texture 색을 추가로 흔들어 fruit confusion 유지 | 생성 단계에서 이미 충분히 흔들었으므로 학습 증강은 낮게 유지 | `--train_low_aug`, mosaic/erasing/auto_augment 제거 |
| hard visibility 비율 높음 | fruit face가 너무 작거나 비스듬한 샘플이 fruit class 학습을 어렵게 만듦 | hard sample은 필요하지만 주력 분포가 되면 안 됨 | hard tier를 5%로 낮추고 hard 하한을 별도 지정 |
| 한 cube 안에 다른 fruit가 섞이는 preview 발견 | `_meta` class와 실제 렌더 texture가 불일치하는 치명적 실패 | 이 상태의 학습은 poison data | face texture/material metadata audit, class-path 검증, unique generated texture 파일 경로로 수정 |
| 한 texture만 반복 | 같은 사진을 외우는 위험, 실제 인쇄물/촬영 변동 부족 | 같은 fruit class 안에서 다양한 texture를 보여야 함 | cube face별 같은 class 다른 texture 허용 |
| 작은 collage texture | 여러 과일을 붙였지만 과일 하나하나가 너무 작아 class cue가 약함 | collage는 좋지만 patch scale이 더 커야 함 | collage patch ratio를 light 기준 0.52~0.70으로 상향 |
| 최종 texture pool | Fruit360만으로는 studio domain이 강하고, crawling만으로는 품질 흔들림 | 고정된 final pool을 만들어 재현성과 다양성을 같이 확보 | `final_fruits36065_original25_fruitseg30_10` 사용 |
| (이후 세대) 목표 재정의 | YOLO 하나로 모든 fruit class를 완벽히 분류하기 어려움 | 먼저 fruit box seg + 깨끗한 class label dataset을 만들고, confusion이 남으면 mask crop 위 lightweight classifier를 올리는 2-stage 검토 | Meta V2 → ABC cascade → Face Classifier(unified)로 발전 (모델 계보는 [HISTORY.md](../HISTORY.md), 중복 기술 생략) |

## 9. Git 관리 기준

Git에 올리는 파일:

```text
source code
README
environment.yml
config/email_smtp.example.json
assets/generated/*.obj
필요한 작은 dataset metadata
필요한 training metadata
최종 checkpoint 일부
```

Git에 올리지 않는 파일:

```text
datasets/ 아래 대형 image/label 산출물
runs/ 아래 대형 학습 산출물
config/email_smtp.json          (비밀번호 포함 가능)
다운로드 cache
루트의 YOLO 기본 모델 파일 (*.pt)
로컬 scratch note
```

현재 `.gitignore`는 `datasets/`, `runs/`, `*.pt`를 기본적으로 무시합니다. 이미 추적 중인 복구 메타데이터와 checkpoint는 예외적으로 Git에 남아 있습니다. (현행 보충: runtime weights는 `jetson/ABC_model/**`에서 **Git LFS**로 추적 — [readme.md](../readme.md) 참조.)

Git 설계 기준은 **"대형 산출물을 저장소에 넣지 않고도 같은 실험을 다시 만들 수 있어야 한다"** 입니다. 그래서 source code, environment, 작은 metadata, checkpoint hash, 실행 명령, quality checklist를 남기고, 수 GB 규모의 image dataset은 로컬 재생성을 전제로 둡니다. 새로운 threshold나 pipeline 판단을 바꾸면 코드만 바꾸지 말고, 왜 바꿨는지 이 문서의 설계 섹션에도 함께 남깁니다.

## 10. 현행 추가사항 (2026-07 기준)

아카이브 복원 범위 밖에서, 2026-07 시점에 데이터 생성 로직에 추가된 것들입니다.

### 10.1 print_label 프로파일 계열

`--fruit_texture_layout`에 `print_label`이 추가됐습니다: 과일 사진을 face 전체에 채우는 대신 **흰 종이/면 위에 인쇄된 라벨처럼** 붙입니다. 실물 경기 물체가 "흰 cube 면 위 소형 인쇄 아이콘"이라는 관찰을 반영한 것입니다. 프로파일은 `--fruit_print_label_profile`로 선택합니다 (2026-07-08 코드 기준 전체 목록):

```text
legacy
realistic_a4_mild
realistic_a4_sparse_icon
realistic_a4_hard
realistic_a4_boundary
realistic_a4_fruit_visible
realistic_a4_label_offset
realistic_a4_label_offset_strong
realistic_a4_label_offset_lqprint
realistic_a4_tape_edge
realistic_a4_tape_edge_visible
realistic_a4_orange_icon_cluster
realistic_a4_orange_icon_cluster_bright
```

최신이자 가장 중요한 프로파일은 **`realistic_a4_sparse_icon`** 입니다 (2026-07-08 확정, [레시피 반복 기록](../reports/cube_face_unified_eval/sparse_icon_probe_iterations_20260708/summary.md)).

- 목적: 실물 recorded 세트의 실패 regime — **흰 면 위 face 면적의 6~16%짜리 sparse 인쇄 아이콘 + webcam 열화** — 를 holdout 없이 Blender로 재현하는 booster.
- patch 선형비(face 대비): light 기준 **0.24~0.40** → 아이콘 면적 ≈ face의 6~16%.
- 인쇄 평탄화: bilateral + k-means(4~6색) **posterize를 75% 확률**로 적용 (`flatten_patch_to_print_icon`).
- 카메라 열화: `--camera_artifact_profile realistic_webcam_hard` (WB/노출/감마/노이즈/저해상 리샘플/vignette/JPEG) 조합이 난이도의 핵심 축.
- 사용 예: `--fruit_texture_layout print_label --fruit_print_label_profile realistic_a4_sparse_icon --camera_artifact_profile realistic_webcam_hard`
- 10k booster: `datasets/cube_face_unified_booster_realistic_a4_mild_coco_sparse_icon_booster_10k_v1` — 현재 preferred 모델의 fruit top-class 오류 16.7%로 recorded 난이도를 재현 (학습/게이트 진행 상태는 [EXPERIMENTS.md](../EXPERIMENTS.md)).

`--camera_artifact_profile` 선택지(§3.3 artifact의 프로파일화): `default / none / mild_exposure / realistic_webcam_hard / realistic_webcam_boundary / webcam_nocolor_mild / webcam_nocolor_strong / webcam_nocolor_aggressive`.

### 10.2 Arena SUN-111/SUN-168 booster

실제 경기장 색(SUN-111 우드 floor / SUN-168 베이지 fence)을 재현하는 booster 생성 모드입니다. **기존 base dataset의 대체가 아니라**, best checkpoint에서의 fine-tune 또는 oversampling mixed fine-tune 전용입니다.

Arena 가정:

```text
floor: SUN-111 beige/yellow wood family with subtle procedural plywood grain
wall/fence: SUN-168 matte beige paint family
camera: low robot-camera view with slight downward pitch
background: 100% synthetic arena floor/wall, no COCO background
fruit sampling inside booster only: apple 30%, orange 30%, banana 20%, pineapple 20%
scene profiles: normal / SUN color shift / motion blur / close-up / plain cube hard negative
```

<details>
<summary>재현 명령 전문 — 3,000장 arena booster 생성 + preview + mixed fine-tune dataset</summary>

```powershell
python scripts\run_yolo_parallel.py `
  --output datasets\arena_sun111_sun168_booster_v1 `
  --num_images 3000 `
  --workers 4 `
  --worker_start_delay 2 `
  --width 640 `
  --height 640 `
  --samples 24 `
  --cpu_threads 1 `
  --label_format segment `
  --min_objects 1 `
  --max_objects 4 `
  --scale_min 0.45 `
  --scale_max 2.20 `
  --negative_ratio 0 `
  --arena_booster_mode `
  --arena_floor_material sun111_wood `
  --arena_wall_material sun168_beige `
  --arena_full_background_ratio 1.0 `
  --robot_camera_view `
  --wall_contact_ratio 0.25 `
  --corner_scene_ratio 0.10 `
  --motion_blur_hard_negative_ratio 0.10 `
  --plain_cube_hard_negative_ratio 0.05 `
  --apple_orange_boost `
  --fruit_texture_aug light `
  --fruit_texture_layout mixed `
  --fruit_texture_collage_prob 0.25 `
  --ideal_visibility `
  --ideal_visibility_debug `
  --ideal_visibility_max_attempts 80 `
  --resume
```

```powershell
python scripts\make_arena_booster_preview_sheets.py `
  --dataset datasets\arena_sun111_sun168_booster_v1 `
  --count 40
```

```powershell
python scripts\make_mixed_finetune_dataset.py `
  --base_dataset datasets\yolo26_seg_100000_ideal_debug `
  --booster_dataset datasets\arena_sun111_sun168_booster_v1 `
  --output datasets\mixed_ideal12000_arena3000_finetune_v1 `
  --base_count 12000 `
  --booster_count 3000 `
  --copy_mode copy `
  --reset
```

mixed dataset은 15,000장에 booster 20% 비율로, 100k + 3k 단순 concat보다 arena 신호가 훨씬 강합니다.

</details>

향후 arena booster의 철학(28-object partial view):

```text
world scene에는 28개 object를 실제처럼 배치한다.
object끼리는 룰북처럼 서로 붙지 않게 한다.
벽 접촉 배치는 허용한다.
camera는 낮은 robot view로 arena 일부만 보게 한다.
학습 frame에는 가까운 object 1~5개, 중거리 일부, 멀리 작은 object 일부가 섞이게 한다.
```

"28개를 한 이미지에 모두 넣는 top-view dataset"이 아니라, **"28개가 깔린 arena를 로봇 시점으로 훑은 partial-view dataset"** 이 목표입니다.

### 10.3 3D mimic arena 렌더러

경기장 최종 공지/실물 사진 기준의 4m x 4m 경기장을 통째로 재현하는 standalone 렌더러가 추가됐습니다.

- 스크립트: [scripts/render_mimic_arena_scene.py](../scripts/render_mimic_arena_scene.py) — SUN-111 우드 바닥(플레이트 이음선 포함), SUN-168 fence 290mm, 알루미늄 코너 플레이트, high-bay LED 4개, 보관함/출발 구역, 28개 object 배치를 [docs/arena_final_environment.md](./arena_final_environment.md) 사양대로 렌더링합니다.
- 환경 사양의 단일 기준 문서: [docs/arena_final_environment.md](./arena_final_environment.md) (공지/실물 사진이 룰북과 다르면 공지/실물 우선).
- 실행 예:

```powershell
C:\Users\user\anaconda3\envs\ai_robotics\Scripts\blenderproc.exe run `
  scripts\render_mimic_arena_scene.py `
  --output reports\arena_mimic_preview_v1 --num_images 10
```

---

변경 이력: 2026-07-08 아카이브(`docs/history/readme_specific_full_20260702.md`)에서 데이터 생성 로직 전체 복원 + 현행 추가사항(§10) 작성.

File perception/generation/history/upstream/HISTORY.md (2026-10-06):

# 프로젝트 역사와 과거 문서 보관소

기준일: 2026-07-08. 이 문서는 두 가지를 담습니다: ① 모델/데이터가 발전해온 서사, ② 과거 문서 정리 과정에서 삭제됐던 내용의 복원 위치.

## 1. 발전 서사 (왜 지금 구조가 되었나)

| 시기 | 일어난 일 | 남긴 교훈 |
| --- | --- | --- |
| 2026-05-14~17 | Blender 합성 데이터 파이프라인 + 8-class object-only YOLO 시작 | 물체는 찾아도 "보이는 면의 과일"을 판단 못함 |
| 2026-05-17~20 | confusion matrix 기반 반복 개선 (yolo26n-seg 전환, texture aug 완화, poison data 발견·audit, texture pool 확정) | "관찰→판단→조치" 기록 문화 정착 (원문: 아카이브 §실험 발전 기록) |
| 2026-05-30 | 실제 경기장 색(SUN-111 우드 floor / SUN-168 베이지 fence) arena booster | booster는 base 대체가 아닌 oversampling fine-tune 전용 |
| 2026-06-22~23 | 경기장 28개 물체(도형 4종×4 + 과일 큐브 4종×3) 해석 확정, visibility-aware Meta V2 + ABC cascade(A1→A2→B→C) + 50k 학습 계획 | robot partial-view 전제; 보이는 픽셀만 라벨링(fruit_vis ≥ 0.10 등 수치 기준) |
| 2026-06-28~29 | A2+B+C를 **Face Classifier(unified)** 하나로 통합, balanced v2 | 다단계 overhead 제거 (ABC 20 FPS → unified 47 FPS 여유) |
| 2026-07-02~04 | verified fruit → flat-icon boundary → HSV stronger + color-outlier pruned 승격 계보 | 실물 webcam 인쇄 아이콘 경계 문제와의 싸움 시작 |
| 2026-07-05~07 | pruning 과잉 진단 → readd base 복구 학습 (**현재 preferred**, best epoch 83) | 게이트 통과 후에만 학습; 실물 세트 61.6→65.1% |
| 2026-07-08 | 실패 원인 = sparse printed-icon composition gap 실증, `realistic_a4_sparse_icon` booster 10k + 학습 진행 | holdout(실물 세트/사용자 사진)은 영구 평가 전용 |

모델 계보 한 줄: `yolo26n-seg → unified v1 → balanced v2 → verified_fruit → flat_icon_boundary → hsv_stronger → hsv_pruned_coloroutlier → readd_coloroutlier_base(현재) → (sparse_icon 진행 중)`

## 2. 과거 문서 복원 보관소

2026-07-02 문서 재작성(`a642db5`) 때 readme_specific.md가 2,500줄→419줄로 축약되며 많은 지식이 삭제됐습니다. **삭제 전 완전판을 그대로 복원해 보관합니다:**

- **`docs/history/readme_specific_full_20260702.md`** — 삭제 직전 완전판 (105KB). 아래 내용의 원문 전체가 여기 있음.
- **`docs/history/readme_full_20260623.md`** — 2026-06-23 시점 readme.

> **2026-07-08 복원 완료**: 아래 표의 **데이터 생성 관련 내용 전부** (visibility 철학/수치, 장면·카메라·distortion 설계, Meta V2 스키마, 권장 기본값 표, 텍스처 파이프라인, 100장 검증/병렬 생성/`--resume`/50k 명령, 실험 발전 기록, Git 기준, arena booster)는 이제 **현행 문서 [docs/DATA_GENERATION.md](./docs/DATA_GENERATION.md)로 복원되어 유지보수됩니다.** 아카이브는 원문 그대로(verbatim) 계속 보관하며, 앞으로의 수정은 DATA_GENERATION.md에만 반영합니다.

### 복원된 내용 찾아보기 (완전판 안의 위치)

| 잃었던 내용 | 요약 | 원문 위치 |
| --- | --- | --- |
| 실험 발전 기록 | confusion 관찰→판단→조치 10행 내러티브 (aug 완화, poison data audit 등) | 완전판 §실험 발전 기록 (L1264~) |
| 50k Meta V2 학습 계획 | `run_meta_v2_50000_training_pipeline.ps1` 7단계 학습 순서, 출력 경로 | 완전판 + `git show 5d2b44b` |
| Visibility 정책 수치 | `obj_vis`/`fruit_vis` 수식, fruit 라벨 기준(`fruit_vis>=0.10`, ≥300px, bbox≥10px), "안 보이면 학습 금지" 철학 | 완전판 §visibility 정책 |
| 권장 기본값 표 | 생성 CLI ~35개 옵션 값+이유, class 가중치, tier 비율 | 완전판 (L1809~) |
| 데이터 생성 운영 문서 | 설치/복구, 텍스처 소스 준비 6단계, 품질 검증, 병렬 생성/`--resume` 설계, 50k 생성 명령, Git 관리 기준 | 완전판 (L1507~2500) |
| 장면/카메라/distortion 설계 | 왜 이렇게 흔들었는가의 근거 | 완전판 (L1358~1441, 1780~) |
| Option 3 전략 분기 (ABC 탄생 논리) | 경기장 28개 물체 해석, Task 분리 기각 근거, 10단계 개발 순서, backup 기준점 | 완전판 (L735~1206) |
| Arena SUN-111/168 booster | 경기장 색 가정과 사용 지침 | 완전판 + `git show 625e0fd:readme.md` |
| GitHub README 버전 통합표 | 18개 commit별 정책 유래 매핑 | `git show 5d2b44b` |
| C 모델 최종화/booster 상세 | anchor pair exp006, whole-fruit booster 실행 전문 | 완전판 + `reports/c_orange_hard_case_experiment_log.md` |

### 기타 보존 문서

- `BACKUP_MANIFEST.md` — 2026-05-16 구세대(8-class) 백업 스냅샷 (커밋/SHA256/재구성 절차). 수정하지 않고 보존.
- `jetson/OPTIMIZATION_EXPERIMENTS.md` — ABC 최적화 실험 E000~E042 전체 로그 (최종 preset `best_stable_5080`, 20-21 FPS / 98.26%).
- `reports/**` — 모든 실험 원본 리포트 (EXPERIMENTS.md가 색인).

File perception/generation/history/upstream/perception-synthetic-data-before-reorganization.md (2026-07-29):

# Synthetic Training Data: How It Was Made, and Why It Worked

**Not one training image was hand-labelled until the night before the finals.** Then an operator relabelled about 74 real crops by eye and dropped 60 more, and that set produced the face weight and the banana/pineapple verifier that played the finals. Every other weight that ran on the
competition robot was trained on scenes rendered by a single BlenderProc script — 4,365
lines of it, with one late exception (§7.6) — and the entire engineering story is the story
of closing the gap between that renderer and a 4 m × 4 m arena floor.

The generation scripts were developed in a separate repository (`Data_Generation_Blender`)
and are referred to below by their names there. The training entry points that consumed
their output are published here under `perception/training/`.

**Contents**

1. [Why synthetic at all](#1-why-synthetic-at-all)
2. [The geometry is analytic](#2-the-geometry-is-analytic)
3. [The fruit cube, and the one decision everything else depends on](#3-the-fruit-cube-and-the-one-decision-everything-else-depends-on)
4. [The render is a hybrid](#4-the-render-is-a-hybrid)
5. [Pixels are dirty, labels are clean](#5-pixels-are-dirty-labels-are-clean)
6. [Visibility gates](#6-visibility-gates)
7. [Honest result 1 — the hue war](#7-honest-result-1--the-hue-war)
8. [Honest result 2 — `val = train` is not a number](#8-honest-result-2--val--train-is-not-a-number)
9. [Honest result 3 — the recognition cliff](#9-honest-result-3--the-recognition-cliff)
10. [The datasets](#10-the-datasets)

---

## 1. Why synthetic at all

The competition objects are 8 cm white 3D-printed polyhedra and 8 cm white cubes with fruit
photographs printed on three faces. Hand-labelling enough of those, under enough lighting
and viewpoint conditions, was not going to happen in the available weeks — and every time
the organisers clarified a rule (the blank face is on the *bottom*, not the side) the whole
label set would have had to change.

Rendering has the opposite cost profile: expensive to build once, free to change. When the
arena rule arrived on 2026-07-18, the fix was three lines
(`FRUIT_FACE_NORMALS` from `{+X, −X, +Y}` to `{+Z, +Y, −Y}`) and a re-render, not a
re-annotation.

The governing design principle, stated in the original documentation, is:

> **Images varied and dirty; labels conservative and clean.**

Camera noise, lighting, blur, JPEG artefacts and background variety are pushed hard. The
labels are computed from the render, from *only the pixels the camera can actually see*,
and are never touched by any of that augmentation.

The visibility policy that follows from it, verbatim from the source docs:

> Do not classify a hidden fruit.
> A cube-like object is not a confirmed plain cube.
> A fruit cube can look like a plain cube in Task 1 too.
> Do not confirm a Task 1 cube pickup from a single view.
> Only a *visible* fruit-face crop counts as fruit-class evidence.

This same rule governs the runtime: a cube whose fruit face is not visible is
`cube_like_unresolved`, not `plain`.

---

## 2. The geometry is analytic

`make_polyhedron_objs.py` (233 lines) writes four OBJs with no modelling and no
dependencies beyond numpy:

- **cube** — the eight ±1 vertices.
- **octahedron** — the six axis vertices.
- **icosahedron** — the golden-ratio vertex set, `φ = (1 + √5)/2`, as
  `(±1, ±φ, 0)`, `(0, ±1, ±φ)`, `(±φ, 0, ±1)`, with the standard 20-triangle face list.
- **dodecahedron** — constructed as the **exact dual of the icosahedron**. Each of the 20
  triangle centroids, normalised to the unit sphere, becomes a dodecahedron vertex; each of
  the 12 icosahedron vertices becomes a pentagonal face, its five adjacent face-centres
  sorted by angle in a plane perpendicular to that vertex's axis.

Every face is then oriented outward (flip the winding if the face normal points away from
the centroid) and every mesh is rescaled so that its **maximum bounding-box extent is
0.08 m** — matching the real 8 cm objects, so the projected pixel size in a render matches
the projected pixel size in the arena.

```bash
python scripts/make_polyhedron_objs.py --out assets/generated --size 0.08
```

The four OBJs total about 24 KB and are checked in, so the pipeline runs without
regenerating them.

---

## 3. The fruit cube, and the one decision everything else depends on

Fruit cubes are not loaded from OBJ. `create_fruit_cube()` builds one:

```python
bpy.ops.mesh.primitive_cube_add(size=0.08, location=[0, 0, 0])   # off-white PLA material
```

and then attaches **three textured quad overlay planes**, one per fruit face, each sitting
**0.45 mm proud of the ±0.040 m cube face**:

```python
def face_vertices_for_normal(normal, half=0.040, offset=0.00045):
```

Each overlay is a separate Blender object carrying its own custom property:

```python
face_obj.set_cp("category_id", FRUIT_FACE_HELPER_CATEGORY_ID)   # 900
```

**This is the decision that makes every downstream gate possible.** Because the printed
faces are separate instances with their own category id, BlenderProc's instance
segmentation map reports **printed-face visibility independently of cube visibility**. The
renderer can therefore answer two different questions about the same object:

```
obj_vis   = visible object mask pixels / full projected object area
fruit_vis = visible fruit-face mask pixels / full projected cube area
```

Without that separation there is no way to express "the cube is clearly visible but its
apple photograph is not", which is exactly the case that must *not* be labelled `apple`.

Class hygiene is enforced at generation time, not in review: if a texture file's declared
class differs from the cube's class, the renderer raises `RuntimeError` and stops. Every
face's texture path and class is written into the per-image metadata. A cube can carry
different *source* textures on its three faces, but they are always the same class.

Fruit-face placement follows the arena rule (2026-07-18):

```python
FRUIT_FACE_NORMALS = [("pos_z", (0,0,1)), ("pos_y", (0,1,0)), ("neg_y", (0,-1,0))]
```

`+Z` is the top; `+Y` and `−Y` are an opposing pair of sides. That is the competition rule
exactly — fruit on the top and on one opposing side pair, blank on the bottom and the other
side pair ([`docs/01-competition-and-rules.md` §3](../../docs/01-competition-and-rules.md)) —
and it makes the robot's top camera the one fruit channel that does not depend on how the
cube was set down.

Cubes are kept mostly upright to match — per-tier tilt of 12°/22°/30°, only 8 % fully
tumbled. The earlier `{+X, −X, +Y}` normals put a blank face on *top*, making the
synthetic top-camera distribution the exact inverse of the real arena's.

White polyhedra get randomised off-white colour and roughness rather than one pure white,
so the model cannot key on a single RGB value.

---

## 4. The render is a hybrid

Each 640×640 image is composited, not rendered end to end:

1. **Cycles renders only the objects**, at 16–48 samples (`--samples`, code default 48,
   production 16). The scene has randomised world colour, key light, fill light and
   optional under-light and ring-light, mixing warm and cool, area/point/sun.
2. The instance mask is softened (`soften_mask()`) to take the edge off the synthetic
   silhouette, and the foreground is **alpha-composited onto a background**: a random crop
   of a COCO 2017 image, or (5 % of scenes, `--arena_background_ratio 0.05`) a procedural
   arena background keyed to the real venue's colours — SUN-111 beige/yellow plywood floor
   with subtle grain, SUN-168 matte beige fence. The background itself gets blur, gain/bias
   and mild texture noise.
3. A **fake shadow** — the object mask, shifted, blurred and used to darken the background —
   is added to **92 %** of scenes. It is not physically correct. Its purpose is to make the
   model comfortable with a dark contact region under an object, which real floors have and
   pure compositing does not.
4. **Negative scenes** (`--negative_ratio 0.18`) contain white cylinders and spheres on
   COCO backgrounds with no labels at all, so "white object ⇒ cube or polyhedron" cannot be
   memorised.

Every object in the arena is a pale, matte, roughly convex solid, which makes "pale convex
blob" an extremely tempting shortcut for the network — and one that would score well on any
validation set drawn from the same renderer. Nearly a fifth of the training set exists to
punish exactly that: decoy spheres and cylinders, rendered with the same materials and
lighting as the real objects, carrying **no labels at all**. The correct answer to those
scenes is silence.

Synthetic training scenes with ground-truth segmentation overlays

*Five labelled scenes and one hard negative. The overlays are written by the renderer, not
by a person. Backgrounds are random COCO photographs because the objects, not the room, are
what the model needs to learn — the arena floor is handled separately by the procedural
background branch above.*

Object placement is not uniform. Some objects are deliberately spawned near existing ones
to create occlusion and near-contact, subject to a minimum centre distance. Each object's
transform is sampled up to **300 times for fruit cubes and 120 times for plain shapes**,
scored on frame margin (0.08), projected area, estimated fruit-face pixels and target
visibility tier; if no perfect candidate is found the best-scoring one is used, so
generation never stalls. Scale is drawn from a **triangular** distribution, not a uniform
one, so small objects exist without dominating.

---

## 5. Pixels are dirty, labels are clean

After compositing, two families of degradation are applied — **to the pixels only.** The
labels come from the segmentation map computed *before* any of it.

### Lens distortion (Brown–Conrady)

`apply_lens_distortion()` draws up to **80 candidate parameter sets**:

```
k1 ∈ [−0.30, 0.22]   k2 ∈ [−0.10, 0.08]   p1, p2 ∈ [−0.006, 0.006]
centre ∈ 0.47–0.53 of the frame,  focal ∈ 0.72–1.15 of the frame
```

A candidate is **accepted only if the remap never samples outside the frame**. If none of
the 80 qualifies, the image simply gets no distortion. This is deliberate: an earlier
version cropped away the invalid black border and rescaled to 640×640, which shifted every
label. The current design would rather lose an augmentation than corrupt a label. Applied
with probability `--lens_distortion_prob 0.35`, and when applied, the image, the instance
segmap and the background are remapped with the *same* map.
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

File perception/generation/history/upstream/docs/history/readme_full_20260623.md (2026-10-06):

# Data Generation Blender

BlenderProc 기반 합성 데이터 생성, YOLO segmentation 학습, 그리고 로봇 경기용 fruit-cube 인식 파이프라인을 실험하는 저장소입니다.

이 문서는 전체 흐름을 빠르게 다시 잡기 위한 요약본입니다. 이전에 고려했던 세부 판단, 폐기한 방향, 실험 로그까지 보려면 [readme_specific.md](./readme_specific.md)를 보세요.

## 한 줄 결론

기존 100k 8-class YOLO 데이터셋을 계속 땜질해서 쓰는 방향은 접고, 앞으로는 Meta V2 metadata를 처음부터 저장하는 새 데이터 생성 구조에서 A1/A2/B/C 모델을 모두 다시 학습하는 방향입니다.

현재 다음 큰 단계는 50k Meta V2 dataset 생성과 A1/A2/B/C 연속 학습입니다.

## 지금까지 한 일
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

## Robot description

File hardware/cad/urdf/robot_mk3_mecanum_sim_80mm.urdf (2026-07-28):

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
<robot name="robot_mk3_mecanum_sim" mecanum_wheel_radius_m="0.04" mecanum_half_length_m="0.15" mecanum_half_width_m="0.125" mecanum_wheel_diameter_mm="80">
  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
  <link name="base_link">
    <inertial>
      <origin xyz="0 0 0.12" rpy="0 0 0"/>
      <mass value="2.4"/>
      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
    </inertial>
    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
  </link>
  <link name="front_left_wheel">
    <inertial>
      <origin xyz="0 0 0" rpy="0 0 0"/>
      <mass value="0.12"/>
      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
    </inertial>
    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
  </link>
  <joint name="front_left_wheel_spin" type="continuous">
    <origin xyz="-0.125 0.15 0.04" rpy="0 0 0"/>
    <parent link="base_link"/>
    <child link="front_left_wheel"/>
    <axis xyz="1 0 0"/>
    <limit effort="1" velocity="35"/>
    <dynamics damping="20.0" friction="0.0"/>
  </joint>
  <link name="front_left_roller_00">
    <inertial>
      <origin xyz="0 0 0" rpy="0 0 0"/>
      <mass value="0.02"/>
      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
    </inertial>
    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
  </link>
  <joint name="front_left_roller_00_joint" type="continuous">
    <origin xyz="0 0 0.025882" rpy="0 0 0"/>
    <parent link="front_left_wheel"/>
    <child link="front_left_roller_00"/>
    <axis xyz="-0.707107 0.707107 0"/>
    <limit effort="1000" velocity="200"/>
    <dynamics damping="0.0001" friction="0.0"/>
  </joint>
  <link name="front_left_roller_01">
    <inertial>
      <origin xyz="0 0 0" rpy="0 0 0"/>
      <mass value="0.02"/>
      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
    </inertial>
    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
  </link>
  <joint name="front_left_roller_01_joint" type="continuous">
    <origin xyz="0 0.009905 0.023912" rpy="0 0 0"/>
    <parent link="front_left_wheel"/>
    <child link="front_left_roller_01"/>
    <axis xyz="-0.707107 0.653281 -0.270598"/>
    <limit effort="1000" velocity="200"/>
    <dynamics damping="0.0001" friction="0.0"/>
  </joint>
  <link name="front_left_roller_02">
    <inertial>
      <origin xyz="0 0 0" rpy="0 0 0"/>
      <mass value="0.02"/>
      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
    </inertial>
    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
  </link>
  <joint name="front_left_roller_02_joint" type="continuous">
    <origin xyz="0 0.018302 0.018302" rpy="0 0 0"/>
    <parent link="front_left_wheel"/>
    <child link="front_left_roller_02"/>
    <axis xyz="-0.707107 0.5 -0.5"/>
    <limit effort="1000" velocity="200"/>
    <dynamics damping="0.0001" friction="0.0"/>
  </joint>
  <link name="front_left_roller_03">
    <inertial>
      <origin xyz="0 0 0" rpy="0 0 0"/>
      <mass value="0.02"/>
      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
    </inertial>
    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
  </link>
  <joint name="front_left_roller_03_joint" type="continuous">
    <origin xyz="0 0.023912 0.009905" rpy="0 0 0"/>
    <parent link="front_left_wheel"/>
    <child link="front_left_roller_03"/>
    <axis xyz="-0.707107 0.270598 -0.653281"/>
    <limit effort="1000" velocity="200"/>
    <dynamics damping="0.0001" friction="0.0"/>
  </joint>
  <link name="front_left_roller_04">
    <inertial>
      <origin xyz="0 0 0" rpy="0 0 0"/>
      <mass value="0.02"/>
      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
    </inertial>
    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
  </link>
  <joint name="front_left_roller_04_joint" type="continuous">
    <origin xyz="0 0.025882 0" rpy="0 0 0"/>
    <parent link="front_left_wheel"/>
    <child link="front_left_roller_04"/>
    <axis xyz="-0.707107 0 -0.707107"/>
    <limit effort="1000" velocity="200"/>
    <dynamics damping="0.0001" friction="0.0"/>
  </joint>
  <link name="front_left_roller_05">
    <inertial>
      <origin xyz="0 0 0" rpy="0 0 0"/>
      <mass value="0.02"/>
      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
    </inertial>
    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
  </link>
  <joint name="front_left_roller_05_joint" type="continuous">
    <origin xyz="0 0.023912 -0.009905" rpy="0 0 0"/>
    <parent link="front_left_wheel"/>
    <child link="front_left_roller_05"/>
    <axis xyz="-0.707107 -0.270598 -0.653281"/>
    <limit effort="1000" velocity="200"/>
    <dynamics damping="0.0001" friction="0.0"/>
  </joint>
  <link name="front_left_roller_06">
    <inertial>
      <origin xyz="0 0 0" rpy="0 0 0"/>
      <mass value="0.02"/>
      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
    </inertial>
    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
  </link>
  <joint name="front_left_roller_06_joint" type="continuous">
    <origin xyz="0 0.018302 -0.018302" rpy="0 0 0"/>
    <parent link="front_left_wheel"/>
    <child link="front_left_roller_06"/>
    <axis xyz="-0.707107 -0.5 -0.5"/>
    <limit effort="1000" velocity="200"/>
    <dynamics damping="0.0001" friction="0.0"/>
  </joint>
  <link name="front_left_roller_07">
    <inertial>
      <origin xyz="0 0 0" rpy="0 0 0"/>
      <mass value="0.02"/>
      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
    </inertial>
    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
  </link>
  <joint name="front_left_roller_07_joint" type="continuous">
    <origin xyz="0 0.009905 -0.023912" rpy="0 0 0"/>
    <parent link="front_left_wheel"/>
    <child link="front_left_roller_07"/>
    <axis xyz="-0.707107 -0.653281 -0.270598"/>
    <limit effort="1000" velocity="200"/>
    <dynamics damping="0.0001" friction="0.0"/>
  </joint>
  <link name="front_left_roller_08">
    <inertial>
      <origin xyz="0 0 0" rpy="0 0 0"/>
      <mass value="0.02"/>
      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
    </inertial>
    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
  </link>
  <joint name="front_left_roller_08_joint" type="continuous">
    <origin xyz="0 0 -0.025882" rpy="0 0 0"/>
    <parent link="front_left_wheel"/>
    <child link="front_left_roller_08"/>
    <axis xyz="-0.707107 -0.707107 0"/>
    <limit effort="1000" velocity="200"/>
    <dynamics damping="0.0001" friction="0.0"/>
  </joint>
  <link name="front_left_roller_09">
    <inertial>
      <origin xyz="0 0 0" rpy="0 0 0"/>
      <mass value="0.02"/>
      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
    </inertial>
    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
  </link>
  <joint name="front_left_roller_09_joint" type="continuous">
    <origin xyz="0 -0.009905 -0.023912" rpy="0 0 0"/>
    <parent link="front_left_wheel"/>
    <child link="front_left_roller_09"/>
    <axis xyz="-0.707107 -0.653281 0.270598"/>
    <limit effort="1000" velocity="200"/>
    <dynamics damping="0.0001" friction="0.0"/>
  </joint>
  <link name="front_left_roller_10">
    <inertial>
      <origin xyz="0 0 0" rpy="0 0 0"/>
      <mass value="0.02"/>
      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
    </inertial>
    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
  </link>
  <joint name="front_left_roller_10_joint" type="continuous">
    <origin xyz="0 -0.018302 -0.018302" rpy="0 0 0"/>
    <parent link="front_left_wheel"/>
    <child link="front_left_roller_10"/>
    <axis xyz="-0.707107 -0.5 0.5"/>
    <limit effort="1000" velocity="200"/>
    <dynamics damping="0.0001" friction="0.0"/>
  </joint>
  <link name="front_left_roller_11">
    <inertial>
      <origin xyz="0 0 0" rpy="0 0 0"/>
      <mass value="0.02"/>
      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
    </inertial>
    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
  </link>
  <joint name="front_left_roller_11_joint" type="continuous">
    <origin xyz="0 -0.023912 -0.009905" rpy="0 0 0"/>
    <parent link="front_left_wheel"/>
    <child link="front_left_roller_11"/>
    <axis xyz="-0.707107 -0.270598 0.653281"/>
    <limit effort="1000" velocity="200"/>
    <dynamics damping="0.0001" friction="0.0"/>
  </joint>
  <link name="front_left_roller_12">
    <inertial>
      <origin xyz="0 0 0" rpy="0 0 0"/>
      <mass value="0.02"/>
      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
    </inertial>
    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
  </link>
  <joint name="front_left_roller_12_joint" type="continuous">
    <origin xyz="0 -0.025882 0" rpy="0 0 0"/>
    <parent link="front_left_wheel"/>
    <child link="front_left_roller_12"/>
    <axis xyz="-0.707107 0 0.707107"/>
    <limit effort="1000" velocity="200"/>
    <dynamics damping="0.0001" friction="0.0"/>
  </joint>
  <link name="front_left_roller_13">
    <inertial>
      <origin xyz="0 0 0" rpy="0 0 0"/>
      <mass value="0.02"/>
      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
    </inertial>
    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
  </link>
  <joint name="front_left_roller_13_joint" type="continuous">
    <origin xyz="0 -0.023912 0.009905" rpy="0 0 0"/>
    <parent link="front_left_wheel"/>
    <child link="front_left_roller_13"/>
    <axis xyz="-0.707107 0.270598 0.653281"/>
    <limit effort="1000" velocity="200"/>
    <dynamics damping="0.0001" friction="0.0"/>
  </joint>
  <link name="front_left_roller_14">
    <inertial>
      <origin xyz="0 0 0" rpy="0 0 0"/>
      <mass value="0.02"/>
      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
    </inertial>
    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
  </link>
  <joint name="front_left_roller_14_joint" type="continuous">
    <origin xyz="0 -0.018302 0.018302" rpy="0 0 0"/>
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

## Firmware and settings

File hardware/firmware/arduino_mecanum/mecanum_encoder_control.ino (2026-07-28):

/*
  Four-wheel mecanum closed-loop controller for Arduino UNO.

  This replaces the open-loop mecanum_pwm_control sketch. It adds four
  quadrature encoders, per-wheel velocity PID (ported from
  encoder_pwm_test.ino), and a cascaded position mode with synchronized
  trapezoidal profiles for precise relative moves.

  Motor drivers: 2x Cytron MDD10A (PWM = speed, DIR = direction,
  sign-magnitude). Pin map (see docs/hardware/mecanum_wiring.md):
    Front-left  motor: D4 = DIR, D5 = PWM   (MDD10A #1 ch M1)
    Front-right motor: D7 = DIR, D6 = PWM   (MDD10A #1 ch M2)
    Rear-left   motor: D2 = DIR, D3 = PWM
    Rear-right  motor: D12 = DIR, D10 = PWM
    Front-left  encoder: A = D8, B = D9     (unchanged from diff base)
    Front-right encoder: A = A0, B = A1
    Rear-left   encoder: A = A2, B = A3
    Rear-right  encoder: A = A4, B = A5
    Spare: D11, D13. D0/D1 reserved for USB serial.

  All four motor PWM pins are hardware PWM (Timer0: D5/D6, Timer2: D3,
  Timer1: D10). Encoders are decoded with pin-change interrupts and a
  quadrature state table, so no external-interrupt pins are required.

  Serial protocol at 115200 baud (one command per line):
    m <vx_mps> <vy_mps> <wz_rad_s>
        Body velocity command (velocity mode). +x forward, +y left, +wz CCW.
    w <fl> <fr> <rl> <rr>
        Wheel angular velocity targets in rad/s (velocity mode).
    d <dx_m> <dy_m> <dyaw_rad>
        Relative body displacement (position mode). Runs a synchronized
        trapezoidal profile on all four wheels, replies "OK move", then
        "DONE,move,..." when settled or "ERR move timeout".
    pw <fl_rad> <fr_rad> <rl_rad> <rr_rad>
        Relative wheel position deltas in rad (position mode).
    p <fl_pwm> <fr_pwm> <rl_pwm> <rr_pwm>
        Direct signed PWM, -255..255 (disables closed loop until next m/w/d).
    pid <kp> <ki> <kd> <min_pwm> <max_pwm> <ff_slope> <integral_limit>
        Velocity PID + feedforward tuning (shared by all wheels).
    ppid <kp> <kd> <max_rad_s> <accel_rad_s2> <tol_rad> <hold_ms> <min_rad_s>
        Position loop tuning.
    geom <wheel_radius_m> <half_length_m> <half_width_m>
        Kinematics geometry used by m/d commands.
    sign <m_fl> <m_fr> <m_rl> <m_rr> <e_fl> <e_fr> <e_rl> <e_rr>
        Per-wheel motor output signs and encoder counting signs (+1/-1).
        Lets bring-up fix wiring polarity without reflashing.
    mstyle <fl> <fr> <rl> <rr>
        Per-wheel PWM encoding (0=DIR_HIGH_PWM_LOW, 1=PWM_HIGH_DIR_LOW).
        Switch driver boards without reflashing (old diff-drive driver =
        `mstyle 0 1 0 1`, MDD10A = `mstyle 1 1 1 1`).
    z       Zero encoder counters.
    stop    Stop all motors, abort any position move.
    stream <0|1>   Enable/disable periodic STATE lines.
    pins    Print pin map.
    test [pwm] [ms]   Drive each wheel forward/reverse in sequence.
    ?       Print help.

  STATE line format (10 Hz when streaming):
    STATE,<ms>,<fl_ticks>,<fr_ticks>,<rl_ticks>,<rr_ticks>,
          <fl_pwm>,<fr_pwm>,<rl_pwm>,<rr_pwm>,<mode>
  where <mode> is 0=idle/pwm, 1=velocity, 2=position.
*/

#include <Arduino.h>
#include <avr/interrupt.h>
#include <util/atomic.h>

enum WheelIndex : uint8_t {
  FL = 0,
  FR = 1,
  RL = 2,
  RR = 3,
  WHEEL_COUNT = 4
};

enum MotorStyle : uint8_t {
  DIR_HIGH_PWM_LOW = 0,  // forward: DIR HIGH, PWM = 255 - duty
  PWM_HIGH_DIR_LOW = 1   // forward: PWM = duty, DIR LOW
};

enum ControlMode : uint8_t {
  MODE_IDLE = 0,
  MODE_VELOCITY = 1,
  MODE_POSITION = 2
};

struct MotorConfig {
  const char *name;
  uint8_t dirPin;
  uint8_t pwmPin;
  MotorStyle style;
};

// Drivers: 2x Cytron MDD10A (2 channels each, sign-magnitude inputs:
// PWM duty = speed, DIR level = direction). ALL channels therefore use the
// PWM_HIGH_DIR_LOW style; the legacy DIR_HIGH_PWM_LOW (inverted-PWM) style
// only applied to the old driver and MUST NOT be used with the MDD10A.
// Per-wheel rotation direction is calibrated with the `sign` command.
const MotorConfig MOTORS[WHEEL_COUNT] = {
  {"front_left", 4, 5, PWM_HIGH_DIR_LOW},
  {"front_right", 7, 6, PWM_HIGH_DIR_LOW},
  {"rear_left", 2, 3, PWM_HIGH_DIR_LOW},
  {"rear_right", 12, 10, PWM_HIGH_DIR_LOW},
};

// Encoder pins. FL stays on the existing D8/D9 wiring (PCINT0, port B).
// FR/RL live on A0-A3 (PCINT1, port C). RR-A moved to D11 (2026-07-14: the
// A4 line read stuck-LOW on the bench, so RR quadrature is split across
// ports — A on PB3, B on PC5 — and decoded via the shared rrPrevState).
const uint8_t ENC_FL_A = 8;   // PB0
const uint8_t ENC_FL_B = 9;   // PB1
const uint8_t ENC_FR_A = A0;  // PC0
const uint8_t ENC_FR_B = A1;  // PC1
const uint8_t ENC_RL_A = A2;  // PC2
const uint8_t ENC_RL_B = A3;  // PC3
const uint8_t ENC_RR_A = 11;  // PB3 (was A4 — dead line)
const uint8_t ENC_RR_B = A5;  // PC5

const float TWO_PI_F = 6.28318530718f;
// JGB37-520 (12V 333rpm): 11 PPR hall x4 decode x1:30 gearbox = 1320.
// Bench-confirmed 2026-07-14 via no-load full-PWM tick rate (~1330 measured).
const float ENCODER_CPR = 1320.0f;
const unsigned long PID_INTERVAL_MS = 20;
const unsigned long REPORT_INTERVAL_MS = 100;
const unsigned long VELOCITY_TIMEOUT_MS = 500;
const unsigned long TEST_STOP_MS = 300;
const float TARGET_DEADBAND_RAD_S = 0.01f;

// Kinematics defaults; overridable with the geom command. Re-measure at the
// wheel contact centers once the mecanum frame is assembled.
// 2026-07-15 LiDAR 실측: 0.034 설정 시 직선 실이동 112~116% → 유효 반경 0.0388.
float wheelRadiusM = 0.0388f;
// 2026-07-15 롤러 X-config 재장착 후 gyro 재캘리브레이션: 유효 (L+W)=0.198
// (real.yaml과 동일, 물리 축간거리 0.150/0.125와 다른 유효값).
// 주의: 이 기본값은 아직 재플래시 안 됨 — 런타임은 브리지 geom push로 적용됨.
float baseHalfLengthM = 0.108f;
float baseHalfWidthM = 0.090f;

// Velocity PID + feedforward, shared across wheels (per-wheel trim happens on
// the ROS side through command scaling if ever needed).
// 2026-07-15 바닥(부하) 튜닝값을 기본값으로 채택 — 벤치 스크립트가 시리얼 오픈
// (UNO 리셋) 직후에도 튜닝 상태로 시작하도록. real.yaml과 동일해야 한다.
float velKp = 10.0f;
float velKi = 8.0f;
float velKd = 0.0f;
float velMinPwm = 10.0f;
float velMaxPwm = 250.0f;
float velFfSlope = 6.9f;
float velIntegralLimit = 20.0f;

// Position loop tuning.
float posKp = 6.0f;            // rad/s per rad of position error
float posKd = 0.0f;
float posMaxRadS = 6.0f;       // profile cruise velocity
float posAccelRadS2 = 12.0f;   // profile acceleration
// 2026-07-15: 0.035(~1mm)는 바닥 부하+RR 단채널 정착 노이즈로 hold 실패가
// 잦아 move timeout을 유발 → 바퀴 ~3mm에 해당하는 0.08로 완화 (real.yaml 동일).
float posToleranceRad = 0.08f;
unsigned long posHoldMs = 150;
// Floor so small errors still break stiction. 0.8은 FL 역방향 데드밴드에
// 못 미쳐 CCW 정착 타임아웃 유발 (2026-07-15) → 1.4.
float posMinRadS = 1.4f;

// 2026-07-14 bench calibration (MK4 mecanum + JGB37-520 + MDD10A): all four
// motors are wired +PWM=reverse, FR/RR encoders have A/B swapped. Baked in as
// defaults so bench scripts (which reset the UNO on serial open) start
// calibrated; the ROS bridge pushes the same values from real.yaml.
int8_t motorSign[WHEEL_COUNT] = {-1, -1, -1, -1};
int8_t encoderSign[WHEEL_COUNT] = {1, -1, 1, -1};

// Runtime-overridable PWM encoding style per wheel (0 = DIR_HIGH_PWM_LOW,
// 1 = PWM_HIGH_DIR_LOW). Defaults match the compile-time MOTORS[].style
// (MDD10A: all PWM_HIGH_DIR_LOW). The `mstyle` command lets bring-up switch
// to a legacy/old-driver board without reflashing, e.g. the diff-drive
// driver's left/right mixed convention `mstyle 0 1 0 1`.
MotorStyle motorStyle[WHEEL_COUNT] = {
  PWM_HIGH_DIR_LOW, PWM_HIGH_DIR_LOW, PWM_HIGH_DIR_LOW, PWM_HIGH_DIR_LOW
};

volatile long ticks[WHEEL_COUNT] = {0, 0, 0, 0};
volatile uint8_t prevPortB = 0;
volatile uint8_t prevPortC = 0;
// RR quadrature state (A<<1)|B spans two ports (A=PB3/D11, B=PC5/A5), so both
// pin-change ISRs update it through this shared variable.
volatile uint8_t rrPrevState = 0;
// 2026-07-14: the RR motor's encoder module has a dead A output (stuck LOW).
// `rr1ch 1` switches RR to single-channel counting: every B edge adds
// rrFbRawDir (+-2 so the effective CPR stays 1320), with the direction taken
// from the last commanded PWM sign. Loses accuracy only around direction
// reversals; disable again after the motor/encoder is replaced.
volatile bool rrSingleChannel = true;  // default ON until the encoder is replaced
volatile int8_t rrFbRawDir = 2;

ControlMode mode = MODE_IDLE;
int currentPwm[WHEEL_COUNT] = {0, 0, 0, 0};
float targetRadS[WHEEL_COUNT] = {0.0f, 0.0f, 0.0f, 0.0f};
float measuredRadS[WHEEL_COUNT] = {0.0f, 0.0f, 0.0f, 0.0f};
float velIntegral[WHEEL_COUNT] = {0.0f, 0.0f, 0.0f, 0.0f};
float velLastError[WHEEL_COUNT] = {0.0f, 0.0f, 0.0f, 0.0f};
long lastPidTicks[WHEEL_COUNT] = {0, 0, 0, 0};

// Position move state.
float moveStartRad[WHEEL_COUNT];
float moveDeltaRad[WHEEL_COUNT];
float movePeakRadS[WHEEL_COUNT];
float moveAccelRadS2[WHEEL_COUNT];
float moveLastPosError[WHEEL_COUNT];
float moveAccelTimeS = 0.0f;
float moveCruiseTimeS = 0.0f;
float moveTotalTimeS = 0.0f;
unsigned long moveStartMs = 0;
unsigned long moveDeadlineMs = 0;
unsigned long moveSettledSinceMs = 0;
bool moveSettling = false;

bool streamEnabled = true;
bool autoRunning = false;
bool abortAuto = false;
unsigned long lastVelocityCommandMs = 0;
unsigned long lastPidMs = 0;
unsigned long lastReportMs = 0;

char commandBuffer[160];
uint8_t commandLength = 0;

static inline int8_t quadratureDelta(uint8_t previousState, uint8_t currentState) {
  // State is encoded as (A << 1) | B.
  static const int8_t table[16] = {
     0,  1, -1,  0,
    -1,  0,  0,  1,
     1,  0,  0, -1,
     0, -1,  1,  0
  };
  return table[(previousState << 2) | currentState];
}

ISR(PCINT0_vect) {
  const uint8_t portB = PINB & (_BV(PB0) | _BV(PB1) | _BV(PB3));  // D8, D9, D11
  const uint8_t changed = portB ^ prevPortB;

  if (changed & (_BV(PB0) | _BV(PB1))) {
    const uint8_t prevState = ((prevPortB & _BV(PB0)) ? 2 : 0) | ((prevPortB & _BV(PB1)) ? 1 : 0);
    const uint8_t currState = ((portB & _BV(PB0)) ? 2 : 0) | ((portB & _BV(PB1)) ? 1 : 0);
    ticks[FL] += quadratureDelta(prevState, currState);
  }
  if (changed & _BV(PB3)) {  // RR-A toggled; B is read live from PC5
    const uint8_t currState = ((portB & _BV(PB3)) ? 2 : 0) | ((PINC & _BV(PC5)) ? 1 : 0);
    ticks[RR] += quadratureDelta(rrPrevState, currState);
    rrPrevState = currState;
  }
  prevPortB = portB;
}

ISR(PCINT1_vect) {
  const uint8_t portC = PINC & 0x3F;  // PC0-PC5 = A0-A5
  const uint8_t changed = portC ^ prevPortC;

  if (changed & (_BV(PC0) | _BV(PC1))) {
    const uint8_t prevState = ((prevPortC & _BV(PC0)) ? 2 : 0) | ((prevPortC & _BV(PC1)) ? 1 : 0);
    const uint8_t currState = ((portC & _BV(PC0)) ? 2 : 0) | ((portC & _BV(PC1)) ? 1 : 0);
    ticks[FR] += quadratureDelta(prevState, currState);
  }
  if (changed & (_BV(PC2) | _BV(PC3))) {
    const uint8_t prevState = ((prevPortC & _BV(PC2)) ? 2 : 0) | ((prevPortC & _BV(PC3)) ? 1 : 0);
    const uint8_t currState = ((portC & _BV(PC2)) ? 2 : 0) | ((portC & _BV(PC3)) ? 1 : 0);
    ticks[RL] += quadratureDelta(prevState, currState);
  }
  if (changed & _BV(PC5)) {  // RR-B toggled; A is read live from PB3 (D11)
    if (rrSingleChannel) {
      ticks[RR] += rrFbRawDir;
    } else {
      const uint8_t currState = ((PINB & _BV(PB3)) ? 2 : 0) | ((portC & _BV(PC5)) ? 1 : 0);
      ticks[RR] += quadratureDelta(rrPrevState, currState);
      rrPrevState = currState;
    }
  }
  prevPortC = portC;
}

long readTicks(uint8_t wheel) {
  long value;
  ATOMIC_BLOCK(ATOMIC_RESTORESTATE) {
    value = ticks[wheel];
  }
  return (long)encoderSign[wheel] * value;
}

float wheelPositionRad(uint8_t wheel) {
  return (float)readTicks(wheel) * TWO_PI_F / ENCODER_CPR;
}

void setMotorPwm(uint8_t wheel, int pwm) {
  if (wheel >= WHEEL_COUNT) {
    return;
  }
  const MotorConfig &motor = MOTORS[wheel];
  if (wheel == RR && pwm != 0) {
    // Single-channel fallback direction. `pwm` here is still the logical
    // command (positive = wheel physically forward); the encoderSign factor
    // keeps the raw count compatible with readTicks() like quadrature would.
    rrFbRawDir = (int8_t)((pwm > 0 ? 2 : -2) * encoderSign[RR]);
  }
  pwm = constrain(pwm * motorSign[wheel], -255, 255);
  currentPwm[wheel] = pwm;

  const uint8_t duty = abs(pwm);
  if (pwm == 0) {
    analogWrite(motor.pwmPin, 0);
    digitalWrite(motor.dirPin, LOW);
    return;
  }

  if (motorStyle[wheel] == DIR_HIGH_PWM_LOW) {
    if (pwm > 0) {
      digitalWrite(motor.dirPin, HIGH);
      analogWrite(motor.pwmPin, 255 - duty);
    } else {
      digitalWrite(motor.dirPin, LOW);
      analogWrite(motor.pwmPin, duty);
    }
    return;
  }

  // MDD10A sign-magnitude: PWM duty = |speed| in BOTH directions, DIR picks
  // the direction. (255 - duty here was a leftover from the legacy
  // inverted-PWM driver and made reverse duty complement the command:
  // full reverse produced duty 0.)
  if (pwm > 0) {
    digitalWrite(motor.dirPin, LOW);
    analogWrite(motor.pwmPin, duty);
  } else {
    digitalWrite(motor.dirPin, HIGH);
    analogWrite(motor.pwmPin, duty);
  }
}

void resetVelocityLoops() {
  for (uint8_t wheel = 0; wheel < WHEEL_COUNT; wheel++) {
    velIntegral[wheel] = 0.0f;
    velLastError[wheel] = 0.0f;
  }
}

void stopMotors() {
  mode = MODE_IDLE;
  moveSettling = false;
  resetVelocityLoops();
  for (uint8_t wheel = 0; wheel < WHEEL_COUNT; wheel++) {
    targetRadS[wheel] = 0.0f;
    setMotorPwm(wheel, 0);
  }
}

float rotationFactor() {
  return baseHalfLengthM + baseHalfWidthM;
}

void bodyToWheels(float vx, float vy, float wz, float out[WHEEL_COUNT]) {
  const float k = rotationFactor();
  out[FL] = (vx - vy - k * wz) / wheelRadiusM;
  out[FR] = (vx + vy + k * wz) / wheelRadiusM;
  out[RL] = (vx + vy - k * wz) / wheelRadiusM;
  out[RR] = (vx - vy + k * wz) / wheelRadiusM;
}

void scaleWheelTargets(float wheels[WHEEL_COUNT], float limit) {
  float peak = 0.0f;
  for (uint8_t wheel = 0; wheel < WHEEL_COUNT; wheel++) {
    peak = max(peak, abs(wheels[wheel]));
  }
  if (peak > limit && peak > 0.0f) {
    const float scale = limit / peak;
    for (uint8_t wheel = 0; wheel < WHEEL_COUNT; wheel++) {
      wheels[wheel] *= scale;
    }
  }
}

// 2026-07-17: 16→30 상향. 16은 r_eff 0.0388 기준 0.62m/s로 모터(무부하
// 34.9rad/s = 1.35m/s)보다 한참 낮은 인위적 캡이었음. 실효 상한은
// real.yaml max_wheel_rad_s(브리지 측 클램프)로 관리한다.
const float MAX_WHEEL_RAD_S = 30.0f;

void enterVelocityMode(const float wheels[WHEEL_COUNT]) {
  float clamped[WHEEL_COUNT];
  for (uint8_t wheel = 0; wheel < WHEEL_COUNT; wheel++) {
    clamped[wheel] = wheels[wheel];
  }
  scaleWheelTargets(clamped, MAX_WHEEL_RAD_S);
  if (mode != MODE_VELOCITY) {
    resetVelocityLoops();
  }
  mode = MODE_VELOCITY;
  moveSettling = false;
  for (uint8_t wheel = 0; wheel < WHEEL_COUNT; wheel++) {
    targetRadS[wheel] = clamped[wheel];
  }
  lastVelocityCommandMs = millis();
}

void startPositionMove(const float deltaRad[WHEEL_COUNT]) {
  float dMax = 0.0f;
  for (uint8_t wheel = 0; wheel < WHEEL_COUNT; wheel++) {
    dMax = max(dMax, abs(deltaRad[wheel]));
  }
  if (dMax < 1e-4f) {
    Serial.println(F("DONE,move,0,0,0,0"));
    return;
  }

  // Trapezoid on the longest wheel; other wheels scale proportionally so all
  // wheels start and finish together.
  float accelTime = posMaxRadS / posAccelRadS2;
  float accelDist = 0.5f * posAccelRadS2 * accelTime * accelTime;
  float peak = posMaxRadS;
  float cruiseTime;
  if (2.0f * accelDist >= dMax) {
    // Triangle profile.
    accelTime = sqrt(dMax / posAccelRadS2);
    peak = posAccelRadS2 * accelTime;
    cruiseTime = 0.0f;
  } else {
    cruiseTime = (dMax - 2.0f * accelDist) / posMaxRadS;
  }

  moveAccelTimeS = accelTime;
  moveCruiseTimeS = cruiseTime;
  moveTotalTimeS = 2.0f * accelTime + cruiseTime;

  for (uint8_t wheel = 0; wheel < WHEEL_COUNT; wheel++) {
    const float ratio = deltaRad[wheel] / dMax;  // signed
    moveStartRad[wheel] = wheelPositionRad(wheel);
    moveDeltaRad[wheel] = deltaRad[wheel];
    movePeakRadS[wheel] = peak * ratio;
    moveAccelRadS2[wheel] = posAccelRadS2 * ratio;
    moveLastPosError[wheel] = 0.0f;
  }

  resetVelocityLoops();
  mode = MODE_POSITION;
  moveSettling = false;
  moveStartMs = millis();
  // 2026-07-15: 정착 여유 1.5s는 바닥 부하에서 빠듯해 timeout 오탐 → 2.5s.
  // 2026-07-19: 접근 단발이동(0.3~0.4m)이 경기장에서 timeout → 파지 허공 CLOSE.
  //   여유 2.5→5.0s (스톨 보호는 유지하되 오탐 억제).
  moveDeadlineMs = moveStartMs
    + (unsigned long)(moveTotalTimeS * 1000.0f) * 2UL
    + 5000UL;
}

// Profile position/velocity for one wheel at elapsed time t.
void sampleProfile(uint8_t wheel, float t, float *posRad, float *velRadS) {
  const float a = moveAccelRadS2[wheel];
  const float vp = movePeakRadS[wheel];
  const float ta = moveAccelTimeS;
  const float tc = moveCruiseTimeS;

  if (t <= 0.0f) {
    *posRad = 0.0f;
    *velRadS = 0.0f;
  } else if (t < ta) {
    *posRad = 0.5f * a * t * t;
    *velRadS = a * t;
  } else if (t < ta + tc) {
    *posRad = 0.5f * a * ta * ta + vp * (t - ta);
    *velRadS = vp;
  } else if (t < moveTotalTimeS) {
    const float td = t - ta - tc;
    *posRad = 0.5f * a * ta * ta + vp * tc + vp * td - 0.5f * a * td * td;
    *velRadS = vp - a * td;
  } else {
    *posRad = moveDeltaRad[wheel];
    *velRadS = 0.0f;
  }
}

int velocityPidStep(uint8_t wheel, float target, float measured, float dt) {
  if (abs(target) < TARGET_DEADBAND_RAD_S) {
    velIntegral[wheel] = 0.0f;
    velLastError[wheel] = 0.0f;
    return 0;
  }
  const float error = target - measured;
  velIntegral[wheel] = constrain(
    velIntegral[wheel] + error * dt,
    -velIntegralLimit,
    velIntegralLimit
  );
  const float derivative = dt > 0.0f ? (error - velLastError[wheel]) / dt : 0.0f;
  velLastError[wheel] = error;

  const float feedforward = velMinPwm + velFfSlope * abs(target);
  float output = feedforward * (target >= 0.0f ? 1.0f : -1.0f)
    + velKp * error
    + velKi * velIntegral[wheel]
    + velKd * derivative;
  output = constrain(output, -velMaxPwm, velMaxPwm);
  return (int)round(output);
}

void finishPositionMove(bool timedOut) {
  stopMotors();
  if (timedOut) {
    Serial.println(F("ERR move timeout"));
    return;
  }
  Serial.print(F("DONE,move"));
  for (uint8_t wheel = 0; wheel < WHEEL_COUNT; wheel++) {
    const float err = moveStartRad[wheel] + moveDeltaRad[wheel]
      - wheelPositionRad(wheel);
    Serial.print(',');
    Serial.print(err, 4);
  }
  Serial.println();
}

void runControlStep() {
  const unsigned long now = millis();
  if (now - lastPidMs < PID_INTERVAL_MS) {
    return;
  }
  const float dt = (now - lastPidMs) / 1000.0f;
  lastPidMs = now;

  // Measure wheel velocities from tick deltas.
  for (uint8_t wheel = 0; wheel < WHEEL_COUNT; wheel++) {
    const long t = readTicks(wheel);
    measuredRadS[wheel] = (float)(t - lastPidTicks[wheel]) * TWO_PI_F
      / ENCODER_CPR / dt;
    lastPidTicks[wheel] = t;
  }

  if (mode == MODE_VELOCITY) {
    if (now - lastVelocityCommandMs > VELOCITY_TIMEOUT_MS) {
      stopMotors();
      Serial.println(F("WARN velocity timeout"));
      return;
    }
    for (uint8_t wheel = 0; wheel < WHEEL_COUNT; wheel++) {
      setMotorPwm(
        wheel,
        velocityPidStep(wheel, targetRadS[wheel], measuredRadS[wheel], dt)
      );
    }
    return;
  }

  if (mode == MODE_POSITION) {
    if (now > moveDeadlineMs) {
      finishPositionMove(true);
      return;
    }
    const float t = (now - moveStartMs) / 1000.0f;
    bool allSettled = true;
    for (uint8_t wheel = 0; wheel < WHEEL_COUNT; wheel++) {
      float profilePos;
      float profileVel;
      sampleProfile(wheel, t, &profilePos, &profileVel);
      const float actual = wheelPositionRad(wheel) - moveStartRad[wheel];
      const float posError = profilePos - actual;
      const float dError = dt > 0.0f
        ? (posError - moveLastPosError[wheel]) / dt
        : 0.0f;
      moveLastPosError[wheel] = posError;

      float velTarget = profileVel + posKp * posError + posKd * dError;

      const float finalError = moveDeltaRad[wheel] - actual;
      const bool profileDone = t >= moveTotalTimeS;
      if (profileDone) {
        if (abs(finalError) > posToleranceRad) {
          allSettled = false;
          // Floor the correction speed so stiction cannot stall the wheel
          // just below the PWM deadband (the diff-drive final-yaw stall).
          if (abs(velTarget) < posMinRadS) {
            velTarget = finalError >= 0.0f ? posMinRadS : -posMinRadS;
          }
        } else {
          velTarget = 0.0f;
        }
      } else {
        allSettled = false;
      }

      // 2026-07-17: MAX_WHEEL_RAD_S(30)가 아니라 이 move의 크루즈 캡으로
      // 클램프. posKp 보정이 무제한 가산되면 max_v를 넘는 폭주 →
      // 종단 급감속/슬립/물체 타격 (16→30 상향 후 실제 발생).
      // 여유 1.15배: 정상 추적 보정은 허용, 폭주만 차단.
      const float vCap = posMaxRadS * 1.15f;
      velTarget = constrain(velTarget, -vCap, vCap);
      targetRadS[wheel] = velTarget;
      setMotorPwm(
        wheel,
        velocityPidStep(wheel, velTarget, measuredRadS[wheel], dt)
      );
    }

    if (allSettled) {
      if (!moveSettling) {
        moveSettling = true;
        moveSettledSinceMs = now;
      } else if (now - moveSettledSinceMs >= posHoldMs) {
        finishPositionMove(false);
      }
    } else {
      moveSettling = false;
    }
  }
}

void printHelp() {
  Serial.println(F("READY mecanum_encoder_control"));
  Serial.println(F("Commands: m <vx> <vy> <wz>, w <fl> <fr> <rl> <rr>, d <dx_m> <dy_m> <dyaw_rad>, pw <fl> <fr> <rl> <rr>, p <fl> <fr> <rl> <rr>, pid <kp> <ki> <kd> <min_pwm> <max_pwm> <ff_slope> <int_limit>, ppid <kp> <kd> <max_rad_s> <accel> <tol_rad> <hold_ms> <min_rad_s>, geom <r> <half_l> <half_w>, sign <m_fl> <m_fr> <m_rl> <m_rr> <e_fl> <e_fr> <e_rl> <e_rr>, mstyle <fl> <fr> <rl> <rr>, z, stop, stream <0|1>, pins, test [pwm] [ms], ?"));
  Serial.println(F("Axes: +x forward, +y left, +wz CCW."));
}
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
void loop() {
  processSerialInput();
  runControlStep();
  maybePrintStatusLine();
}

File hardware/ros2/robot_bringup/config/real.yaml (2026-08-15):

motor_bridge_node:
  ros__parameters:
    serial_port: /dev/serial/by-id/usb-Arduino__www.arduino.cc__Arduino_14101-if00
    serial_port_candidates: /dev/serial/by-id/usb-Arduino__www.arduino.cc__Arduino_14101-if00,/dev/serial/by-path/platform-3610000.usb-usb-0:2.3.1:1.0,/dev/ttyACM0
    serial_reconnect_interval_sec: 1.0
    serial_boot_delay_sec: 0.5
    serial_write_timeout_sec: 0.1
    cmd_vel_topic: /cmd_vel
    e_stop_topic: /safety/e_stop
    odom_topic: /odom/wheel
    odom_frame: odom
    base_frame: base_footprint
    publish_tf: false
    wheel_radius_m: 0.044
    wheel_separation_m: 0.25
    encoder_cpr: 2464
    left_encoder_sign: 1
    right_encoder_sign: -1
    swap_wheel_commands: true
    swap_wheel_odometry: true
    max_linear_mps: 0.16
    max_angular_rps: 0.30
    calibration_csv: hardware/calibration/motor_pwm/latest_pwm_calibration.csv
    min_calibration_points: 2
    min_calibration_duration_sec: 2.0
    min_pwm: 72.0
    max_pwm: 220.0
    feedforward_slope: 18.5
    left_pwm_scale: 1.0
    right_pwm_scale: 1.0
    speed_kp: 12.0
    speed_ki: 7.0

# Mecanum conversion. Activated with drive_type:=mecanum on
# real_competition_bridge.launch.py; pairs with
# hardware/firmware/arduino_mecanum. Geometry values are
# pre-assembly estimates -- re-measure wheel radius and contact-center
# half length/width after the mecanum frame is built.
mecanum_bridge_node:
  ros__parameters:
    serial_port: /dev/serial/by-id/usb-Arduino__www.arduino.cc__Arduino_14101-if00
    serial_port_candidates: /dev/serial/by-id/usb-Arduino__www.arduino.cc__Arduino_14101-if00,/dev/serial/by-path/platform-3610000.usb-usb-0:2.3.1:1.0,/dev/ttyACM0
    serial_reconnect_interval_sec: 1.0
    serial_boot_delay_sec: 2.0
    serial_write_timeout_sec: 0.1
    cmd_vel_topic: /cmd_vel
    move_relative_topic: /base/move_relative
    move_result_topic: /base/move_result
    e_stop_topic: /safety/e_stop
    odom_topic: /odom/wheel
    odom_frame: odom
    base_frame: base_footprint
    publish_tf: false
    # 2026-07-15 LiDAR 실측 보정: 0.034 설정 시 전/후진 실이동이 112~116%
    # (logs/mecanum_bringup/move_accuracy_021329.json) → 유효 접지 반경 0.0388.
    wheel_radius_m: 0.0388
    # 2026-07-15 롤러 X-config 재장착 후 gyro 재캘리브레이션: 유효 회전 기하
    # (L+W)=0.198 (물리 0.275보다 작음 — dyaw 90도 명령이 158도 실회전).
    # 유효값이므로 실축간거리와 다름. 바퀴/바닥 바뀌면 51_move_accuracy_lidar로 재측정.
    half_length_m: 0.108
    half_width_m: 0.090
    encoder_cpr: 1320  # JGB37-520 실측(무부하 tick rate) = 스펙 11PPRx4x30 (2026-07-14)
    # 2026-07-14 브링업 실측: 4모터 모두 +PWM=후진 배선 → 전부 -1.
    # FR/RR 엔코더 A/B 반전 (RR은 A4 단선 수리 후 판정).
    motor_signs: [-1, -1, -1, -1]
    encoder_signs: [1, -1, 1, -1]
    # 2026-07-17 속도 캡 상향: 기존 0.24/0.20/0.8/12는 초기 브링업 안전값.
    # 펌웨어 MAX_WHEEL_RAD_S 16→30 상향과 함께 개방 (모터 무부하 34.9rad/s).
    # 실효 상한은 경기장 엔벨로프 재측정으로 확정할 것.
    max_linear_x_mps: 0.9
    max_linear_y_mps: 0.6
    max_angular_rps: 2.0
    max_wheel_rad_s: 26.0
    command_timeout_sec: 0.5
    # 2026-07-14 JGB37-520 블록 스텝 튜닝 (logs/mecanum_bringup/pid_235827) 후
    # 2026-07-15 바닥(부하) 재튜닝 (logs/mecanum_bringup/pid_verify_0137*):
    # 무부하 게인(ki=5, min_pwm=8, int_limit=8)은 바닥 저속에서 FL이 -18%까지
    # 처짐 → ki/적분한계/min_pwm 증량. 3/6/9 rad/s 전·후진 steady err<±6%,
    # rise(정지 출발)<0.6s. RR은 B상 단채널(rr1ch) 상태로 합격.
    # ff_slope는 오픈루프 스윕 실측 (logs/mecanum_bringup/openloop_sweep.json).
    speed_kp: 10.0
    speed_ki: 8.0
    speed_kd: 0.0
    min_pwm: 10.0
    max_pwm: 250.0
    feedforward_slope: 6.9
    integral_limit: 20.0
    position_kp: 6.0
    position_kd: 0.0
    # 2026-07-17: 가속 12→24 상향 (45도 회전 1.3→0.8s 목표, 소이동 재검증 필요)
    position_max_rad_s: 6.0
    position_accel_rad_s2: 24.0
    # 2026-07-15: 0.035(바퀴 1.2mm)는 바닥 부하 + RR 단채널 정착 노이즈에서
    # 스트레이프/회전 move가 hold를 못 채워 timeout → 0.08(바퀴 ~3mm)로 완화.
    # 2026-07-16: 0.08도 소이동/회전 정지마찰 진동 밖 → 잦은 4.9s 타임아웃
    # (경기장 E2E: 회전 8회 중 3회, 접근 정렬 이동). 0.20(바퀴 ~7.8mm,
    # 회전 ~2.2도)으로 과감히 상향 — 파지 허용 ±55mm 대비 수용 가능.
    # 2026-07-20: 운반 부하(물체 파지 후진/적재 전·후퇴)에서 0.20도 재발 —
    # E2E 3런에서 단발이동 절반이 정착 실패로 데드라인(5s+) 소진, 런당
    # 36~74s 손실. 0.30(바퀴 ~11.7mm) + hold 100→50ms로 완화. 타임아웃
    # 후에도 러너는 진행하고 적재 5/5 성공했으므로 실효 정밀도는 동일,
    # 대기 시간만 회수하는 조치. 벤치 -0.2m 후진 ×20 재검증 예정.
    position_tolerance_rad: 0.30
    position_hold_ms: 50
    # 2026-07-15: 0.8이면 정착 FF(min_pwm+ff*0.8=15pwm)가 FL 역방향 데드밴드에
    # 못 미쳐 CCW 회전 정착이 적분 감길 때까지 수 초 지연/타임아웃 → 1.4로 상향.
    position_min_rad_s: 1.4
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

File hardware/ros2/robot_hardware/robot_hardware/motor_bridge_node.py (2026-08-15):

#!/usr/bin/env python3

import json
import math
import glob
import os
import time
from pathlib import Path

import rclpy
import serial

from geometry_msgs.msg import Quaternion, TransformStamped, Twist
from nav_msgs.msg import Odometry
from rclpy.node import Node
from sensor_msgs.msg import JointState
from std_msgs.msg import Bool, String
from tf2_ros import TransformBroadcaster

from robot_hardware.base_control import (
    DifferentialOdometry,
    EncoderSample,
    WheelPiController,
    load_pwm_calibration,
    parse_encoder_line,
    summarize_pwm_calibration,
    twist_to_wheel_speeds,
)

REPO_ROOT = Path(__file__).resolve().parents[4]
DEFAULT_CALIBRATION_CSV = (
    'hardware/calibration/motor_pwm/'
    'pwm_encoder_sweep_20260527_231622_speed_analysis.csv'
)


def resolve_repo_path(path_value):
    path = Path(str(path_value)).expanduser()
    if path.is_absolute():
        return path
    return REPO_ROOT / path


def yaw_to_quaternion(yaw):
    half = yaw * 0.5
    return Quaternion(z=math.sin(half), w=math.cos(half))


class MotorBridgeNode(Node):
    def __init__(self):
        super().__init__('motor_bridge_node')

        self.declare_parameter(
            'serial_port',
            '/dev/serial/by-id/'
            'usb-Arduino__www.arduino.cc__Arduino_14101-if00',
        )
        self.declare_parameter(
            'serial_port_candidates',
            '/dev/serial/by-id/usb-Arduino__www.arduino.cc__Arduino_14101-if00,'
            '/dev/serial/by-path/platform-3610000.usb-usb-0:2.3.1:1.0,'
            '/dev/ttyACM0',
        )
        self.declare_parameter('baudrate', 115200)
        self.declare_parameter('serial_reconnect_interval_sec', 1.0)
        self.declare_parameter('serial_boot_delay_sec', 0.5)
        self.declare_parameter('serial_write_timeout_sec', 0.1)
        self.declare_parameter('dry_run', False)
        self.declare_parameter('cmd_vel_topic', '/cmd_vel')
        self.declare_parameter('e_stop_topic', '/safety/e_stop')
        self.declare_parameter('odom_topic', '/odom/wheel')
        self.declare_parameter('odom_frame', 'odom')
        self.declare_parameter('base_frame', 'base_footprint')
        self.declare_parameter('publish_tf', False)
        self.declare_parameter('wheel_radius_m', 0.044)
        self.declare_parameter('wheel_separation_m', 0.25)
        self.declare_parameter('encoder_cpr', 2464)
        self.declare_parameter('left_encoder_sign', 1)
        self.declare_parameter('right_encoder_sign', -1)
        self.declare_parameter('left_motor_sign', 1)
        self.declare_parameter('right_motor_sign', 1)
        self.declare_parameter('swap_wheel_commands', False)
        self.declare_parameter('swap_wheel_odometry', False)
        self.declare_parameter('max_linear_mps', 0.30)
        self.declare_parameter('max_angular_rps', 1.20)
        self.declare_parameter('max_wheel_rad_s', 8.0)
        self.declare_parameter('command_timeout_sec', 0.5)
        self.declare_parameter(
            'calibration_csv',
            DEFAULT_CALIBRATION_CSV,
        )
        self.declare_parameter('min_calibration_points', 2)
        self.declare_parameter('min_calibration_duration_sec', 2.0)

        # Feedforward values come from the 2026-05-27 unloaded sweep.
        # PI feedback supplies the extra PWM needed after payload increases.
        self.declare_parameter('min_pwm', 72.0)
        self.declare_parameter('max_pwm', 220.0)
        self.declare_parameter('feedforward_slope', 18.5)
        self.declare_parameter('left_pwm_scale', 0.92)
        self.declare_parameter('right_pwm_scale', 1.08)
        self.declare_parameter('speed_kp', 12.0)
        self.declare_parameter('speed_ki', 7.0)
        self.declare_parameter('integral_limit', 8.0)

        self.wheel_radius = float(
            self.get_parameter('wheel_radius_m').value
        )
        self.wheel_separation = float(
            self.get_parameter('wheel_separation_m').value
        )
        self.encoder_cpr = int(self.get_parameter('encoder_cpr').value)
        self.left_encoder_sign = int(
            self.get_parameter('left_encoder_sign').value
        )
        self.right_encoder_sign = int(
            self.get_parameter('right_encoder_sign').value
        )
        self.left_motor_sign = int(
            self.get_parameter('left_motor_sign').value
        )
        self.right_motor_sign = int(
            self.get_parameter('right_motor_sign').value
        )
        self.swap_wheel_commands = bool(
            self.get_parameter('swap_wheel_commands').value
        )
        self.swap_wheel_odometry = bool(
            self.get_parameter('swap_wheel_odometry').value
        )
        self.max_linear = float(
            self.get_parameter('max_linear_mps').value
        )
        self.max_angular = float(
            self.get_parameter('max_angular_rps').value
        )
        self.max_wheel_speed = float(
            self.get_parameter('max_wheel_rad_s').value
        )
        self.command_timeout = float(
            self.get_parameter('command_timeout_sec').value
        )
        self.dry_run = bool(self.get_parameter('dry_run').value)
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

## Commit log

2026-07-28 DDONGGAE — SNU AI ROBOT CHALLENGE 2026, 1st of 16 teams
    An autonomous mobile manipulator that finds, identifies, grasps and stores 8 cm
    objects in a 4 m x 4 m arena inside a 3-minute round, with no Nav2, no AMCL, no
    TF tree and not one hand-labelled training image.
    This is the code that played the four matches, the perception pipeline and the
    synthetic-data recipe behind it, the hardware it ran on, and an Isaac Sim
    kinematic surrogate of the arena.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
    [base_link.stl, battery.stl, jetson_orin_nano.stl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]
2026-07-29 Docs: cube face rule, mast rationale, and hardware reliability notes
    Set 2 face layout and what follows from it, why the mast is raised for the
    centre scan, the USB hub and 12 V power-on order, the organisers' arena figure,
    and credits.
2026-07-31 Docs: centred README hero with badges and section nav
    Rebuild the top of the README as a centred hero block: the acronym as a
    subtitle, the one-line pitch, the result, a trimmed badge row (result and
    licence, then OS/runtime, then the software stack at the versions pinned in
    docs/08-reproducibility.md), the match photograph as the lead image, and a
    row of links into the three parts and the docs.
    The competition photograph moves up into the hero, so the strip below now
    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
2026-08-15 Fix path regressions introduced by the public-release re-layout
    Files moved into the part-directory layout (hardware/, perception/,
    navigation/, mission/, scripts/) but their repo-root computations and
    cross-references were not updated with them. None of this was caught
    because the released tree was never executed.
    Blocking:
    - scripts/run_match_day.sh: REPO_ROOT used ../.. from scripts/, i.e. the
    parent of the repo, so the match-day one-liner exited 1 with
    "runner not found" and warned about a missing colcon workspace it was
    looking for in the wrong place.
    - perception/fieldlib.py: BridgeManager.launch_stack pointed at
    scripts/dev/run_lightweight_arena_control.sh. launch_stack retur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
    [30_pid_step_tune.py, gripper_record_limit.py, motor_bridge_node.py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]
2026-08-15 Derive the arena from the map instead of hard-coding it in four places
    Groundwork for running the same stack on a smaller arena. Nothing changes
    behaviourally: the competition map, its 42 grid points and every published
    value are identical before and after.
    - maps/make_arena_map.py: the occupancy map had no generator, so a different
    arena size could not be produced at all. Reproducing the competition PGM
    byte-for-byte is the acceptance test the tool ships with:
    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
2026-08-15 Make the arena one constant, and publish what the runner is thinking
    Checkpoint from two parallel work streams. Behaviour on the competition
    profile is unchanged: every derived constant is bit-identical to the literal
    it replaced, and the match-day defaults still produce the same run.
    Arena geometry -- one source instead of scattered literals
    ----------------------------------------------------------
    The half-arena offset was written as a bare +/-2.0 in the runner, the grid
    table existed in several copies, and one of those literals sits inside the
    approach-stage grid snap gate, which rejects a detection whose back-projected
    cell does not match the target cell. That gate is load-bearing: it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
2026-08-15 Add SNU and Mechanical Engineering logos for the spectator display
    The demo runs as a public booth, so the audience screen carries the
    university and department marks in its top bar. Both files come straight
    from the official wordmarks, unmodified.
    They also set the screen's palette: the navy (#203080) sampled from the
    SNU mark is the accent, and the orange (#e88820) from the Mechanical
    Engineering mark colours the robot and its current target, so the orange
    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
2026-08-15 Derive the offline self-test expectations from the grid
    The self-test asserted against coordinates that only exist in a 4 m arena --
    cells like (150,200), the snap probe (152,197)->(150,200), a mini-goal
    expectation of (+0.25,-0.75), street snap candidates written as -1.25+0.5k,
    and the descend candidate column pinned to x=250. On any other arena those
    are not wrong answers, they are questions that no longer have answers: the
    GT parser correctly rejects a cell outside its grid, so the self-test died
    on its first fixture rather than reporting anything useful.
    Each expectation now comes from the same constants the code under test uses:
    fixtures pick real cells out of GRID_*_CM, the snap probe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
2026-08-15 Skip the drive when already at the scan point, and refuse a mismatched arena
    Two guards that are dead code in the competition geometry and load-bearing
    in the 2 m demo.
    stage_goto_center now returns immediately when the robot is already within
    20 cm of the scan point. On the 4 m field start and scan point sit 2.57 m
    apart so the branch never fires. The demo scans from the start pose, where
    without this the first leg drives 0.4 m north onto the highway and the
    second leg drives the same distance back south, because the scan point now
    lies south of the highway line. The tolerance clears the localiser's 7.5 cm
    quantisation on both axes and stays well inside the 50 cm street spacing.
    stage_see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
2026-08-15 2 m demo profile
    Same code as main, different arena. The diff against main is 45 lines and
    contains no logic: the C-stage work made every dependent value derive from
    ARENA_HALF_M, so this branch only states what is actually different about
    the venue.
    - Arena 4 m -> 2 m, candidate grid 7x6=42 -> 3x2=6. The 50 cm pitch and the
    wall margins are deliberately unchanged: street clearance of 11.5 cm and
    the +/-25 cm mini-goal offset are both derived from that pitch and were
    tuned on the real robot. Shrinking the pitch would invalidate street_nav's
    gains and tolerances wholesale, so the number of points shrinks, not the
    spacing.
    - The scan happens at the start pose instead of near the ar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
2026-08-15 Point the node defaults at the demo map too
    The launch file was switched to demo2m.yaml but the nodes' own
    default_map_yaml() still said stadium.yaml, so starting arena_control_node
    with ros2 run on this branch loaded the 4 m map and published half_m 1.99
    against a runner believing 1.00. The arena agreement check would have caught
    it at seed time, which is the point of that check, but there is no reason to
    ship a branch that disagrees with itself.
2026-08-16 Derive the mini-goal sweep count from the grid
    The sweep already iterated fl.GRID_XS_CM x fl.GRID_YS_CM, but the line it
    printed said "42셀" no matter what the grid held. On the 2 m demo profile
    that reported 42 cells while checking 6, directly contradicting the
    "격자 3x2=6칸" line the profile section prints a few rows later.
    Same treatment as the descend expectations in bb35ea6 — the count is now
    computed from the grid, so it reads 42 on the competition profile and 6 on
    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
2026-08-16 Let the spectator screen start a match
    The booth runs one machine and one screen, so having to drop to a terminal to
    pick targets and launch the runner was the awkward part of a demo. The idle
    overlay now carries a target picker and a start button, and the server spawns
    match_runner.py with what was picked.
    Off by default. The module docstring calls this screen read-only and says the
    match survives it dying; a start button contradicts both, and every device on
    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
2026-10-06 Integrate perception data generation pipeline
    [dodecahedron.obj, icosahedron.obj, octahedron.obj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]
2026-10-06 Fix fruit texture classes and cube print faces

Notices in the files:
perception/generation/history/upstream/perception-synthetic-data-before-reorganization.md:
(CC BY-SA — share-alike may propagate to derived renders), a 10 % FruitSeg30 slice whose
